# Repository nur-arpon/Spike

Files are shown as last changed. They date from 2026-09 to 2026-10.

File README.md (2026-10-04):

# Spike

**A desk robot dog with a face, a memory and a personality, and the apps that bring him to life.**

Spike (the hardware project is called *Desk Buddy*) is a small four-legged companion that lives on your
desk. His face is a 4.3-inch touch screen. He hears you, sees you, remembers what you tell him, wakes you
up, teases you when you're fine and goes gentle when you're not. When he's away from the robot body, the
same character lives on your phone and your Windows PC.

> **All rights reserved. This repository is source-available for viewing only.**
> No licence is granted to copy, modify, build, distribute or use any part of it. See [LICENSE](LICENSE).
> Third-party components keep their own licences: see [THIRD_PARTY_NOTICES.md](THIRD_PARTY_NOTICES.md).

<p align="center">
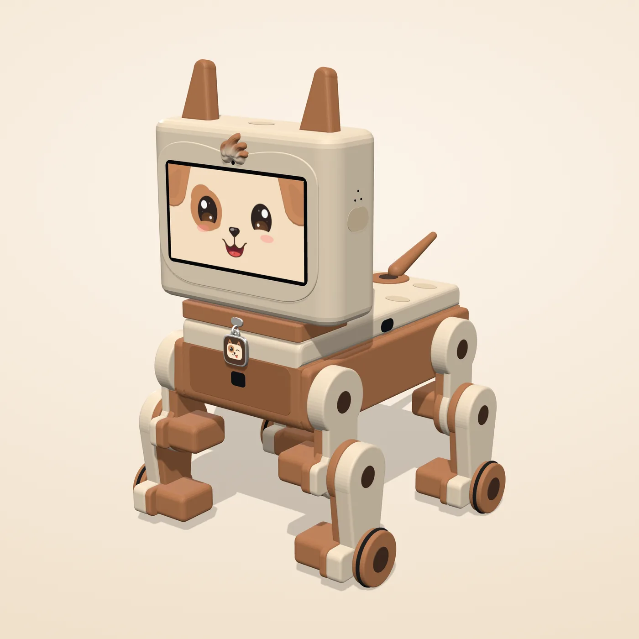
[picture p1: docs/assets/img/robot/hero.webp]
Spike, the desk robot (v3.2 design)
  
</p>

## What's in here

| Part | Folder | What it is |
|---|---|---|
| **Face** | `software/face_v2/`, `software/face/` | The animated character face (Spike the pup, Spicy the cat): moods, expressions, games, captions and sounds, drawn procedurally. A browser build doubles as the reference the firmware is tested against. |
| **Brain** | `software/laptop/spike_brain/` | The mind that runs on your own computer: wake words, speech recognition, conversation, persona, long-term memory, alarms and reminders, vision events and a natural voice. Private by design: speech, vision and memory stay on the laptop. |
| **Firmware** | `software/firmware/` | ESP32-S3 firmware for the two boards: the screen board (face renderer, body control, gait, sensors, Bluetooth LE and Wi-Fi link) and the camera board. Pixel-checked against the browser face. |
| **Protocol** | `software/protocol/` | The one contract between robot, brain and apps: message types, the BLE framing and the test vectors every side checks itself against. |
| **App** | `software/app/spike_app/` | One Flutter codebase for Android and Windows. Pair and talk to Spike, drive him, teach him tricks, design faces in the Face Studio, set alarms, see what he remembers and make him forget, and meet him in 3D. On the phone he can also run "away" with an on-device brain. |
| **CAD** | `cad/` | The printed body, generated by Python scripts driving SolidWorks: every part, the bought-parts model, full assemblies, STL exports, renders and build reports, versions v1 to v3.2. |
| **Assembly guide** | `guide/` | The illustrated build guide (PDF), generated from the CAD and the parts list. |
| **3D previews** | `preview_3d/` | Interactive shell-design previews used to choose the look. |
| **Website** | `docs/` | The official site, published with GitHub Pages at <https://nur-arpon.github.io/Spike/>. How to post an update: [docs/UPDATING.md](docs/UPDATING.md). |

## A look at it

<p align="center">
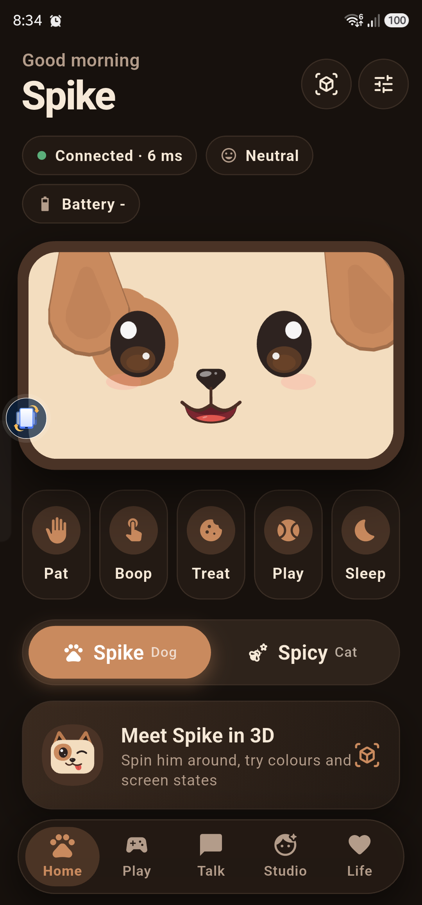
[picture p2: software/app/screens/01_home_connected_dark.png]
Spike app, home screen
  
  &nbsp;
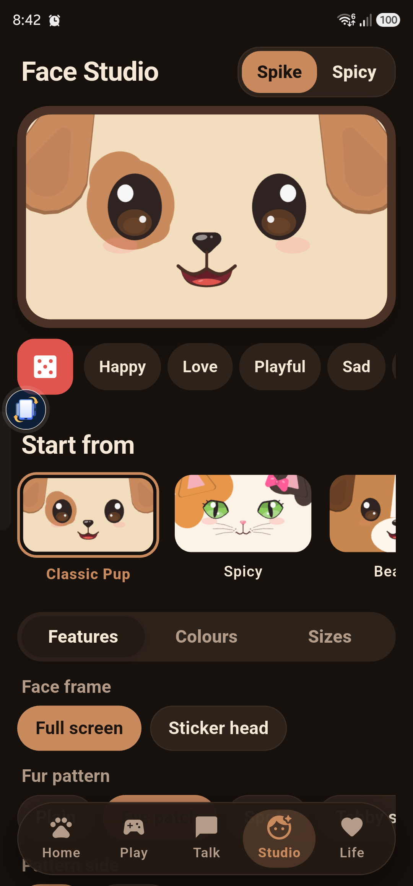
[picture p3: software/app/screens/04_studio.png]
Face Studio
  
  &nbsp;
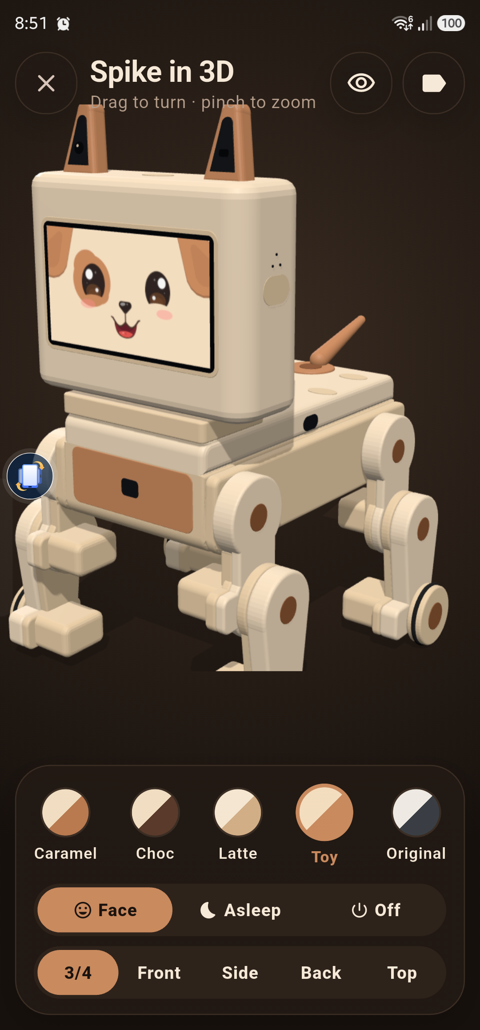
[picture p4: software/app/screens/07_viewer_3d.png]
Spike in 3D
  
</p>

<p align="center">
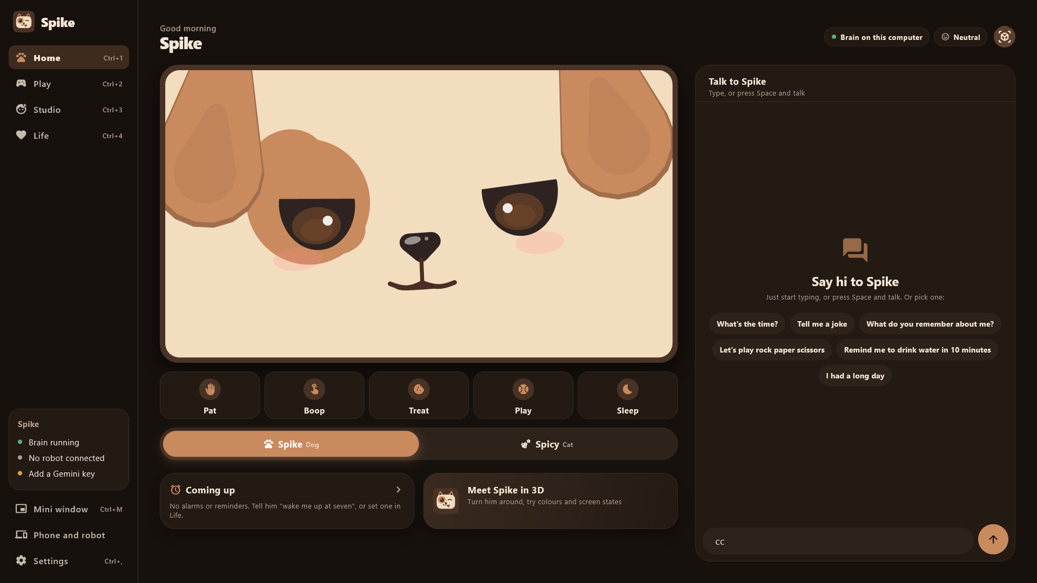
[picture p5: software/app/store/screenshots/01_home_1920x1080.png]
Spike for Windows
  
</p>

## The hardware, briefly

- **Head:** ESP32-S3 board with a 4.3-inch capacitive touch screen, two microphones, a speaker and a touch pad.
- **Camera:** a second ESP32-S3 with an OV5640 camera, its lens under a tuft of fur in the middle of the forehead; a gesture sensor sits in the chest.
- **Body:** thirteen micro servos (hips, knees, wheel paws and a tail) on two PWM drivers, an IMU, capacitive
  touch pads, and time-of-flight sensors that stop him at the desk edge. Desk-edge stops live in the
  firmware and cannot be turned off from any app.
- **Power:** a single 18650 cell with protection, a fuse and USB-C charging.
- **Shell:** fully 3D-printed in two colours; every servo, horn, screw and wire is hidden inside.

## Privacy

Spike's brain runs on the owner's own computer. There are no accounts, no ads and no tracking. The app's
privacy policy is published at **<https://nur-arpon.github.io/Spike/privacy-policy.html>**.

## Status

Active development, 2026. Follow along at <https://nur-arpon.github.io/Spike/updates.html>.

- App 1.0.1 (Android and Windows) and the laptop brain run together today.
- Firmware for both boards builds, and its protocol and face-rendering tests pass.
- The v3.2 body (one screen face, camera under a forehead tuft) is designed and checked; the first print is next.

## Licence

Made by Nur Ifran Arpon · SpaceZ.

Copyright (c) 2026 Nur Ifran Arpon (SpaceZ). All rights reserved. Viewing only; see [LICENSE](LICENSE).
For licensing enquiries, open an issue.

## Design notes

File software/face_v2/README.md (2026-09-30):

# Spike's face, version 2

This folder is the new face for Spike, and for Spicy, his cat side. It runs in your web browser as a simulator of the robot's little screen. Everything works offline. There are no downloads and no internet calls, and every sound is made live by the browser.

Version 1 is still in the folder next to this one, called "face". Nothing in it was changed.

## How to open it

Double-click the file called index dot html. It opens in your browser. There is nothing to install.

## What is new in version 2

The face sits lower on the screen now, the way baby animals look. The eyes are just below the middle, and the nose and mouth are tucked in close underneath.

Nothing joins the two eyes any more. The line that looked like the rim of glasses is gone. There is a test that checks this every time.

The default face is your toy puppy. It has cream fur, a brown patch around one eye, big glossy dark eyes with two shiny highlights, a wet dark nose, a big smile with a red tongue, and floppy brown ears in the top corners.

Spicy has her own face. She is a calico cat, which is a nice touch, because calico cats are almost always girls. She has green cat eyes with eyelashes, a pink nose, a little "w" shaped mouth, whiskers and a pink bow. When she's calm she looks at you with half-closed, knowing eyes.

## Why it looks alive

Nothing on the face ever snaps. Every part moves like it is on a soft spring, so it overshoots a little and settles, the way a cartoon character moves.

When Spike blinks, his eyes squash shut and then stretch a little as they spring open. Sometimes he blinks twice.

His eyes make tiny darting movements all the time, and bigger glances now and then. The shiny spots in his eyes stay put as he looks around, like real reflections.

He breathes with a slow gentle bob. His ears flick now and then, and they swing when he tilts his head. He sniffs in little bursts of three, and his nose twitches when he's curious. Now and then he tilts his head at you.

When he is really happy, his cheeks push his eyes up into happy closed arcs. When he is sad, his eyes get watery with a wobbling waterline and extra sparkles.

## Touching the face

Click anywhere on the face to give him a head pat. His eyes close happily, his ears go flat, and little hearts pop up. If you pat too fast he gets dizzy. Spicy only puts up with a few pats before she gets cross and hisses.

Click his nose to boop it. He goes cross-eyed looking at his own nose, then giggles.

Move your mouse around and his eyes follow you. On the real robot the camera will do this.

## The panel on the right

The panel has four tabs.

Moods has one button for every mood. There are forty-three of them, from happy and sad to jealous, smug, awe and hungry. Each mood has its own little motion, so none of them is a still picture. "Play all moods" steps through every one.

Actions has the physical actions. They are wake up, fall asleep, nap, doze off, dream, trip, sneeze, hiccups, shiver, pant, happy dance, zoomies, head tilt, sniff around, beg, roll over and play bow. Each one also sends a body label, which the robot's legs and wheels will use later. You can see the label under the buttons while an action plays.

Life has the everyday things. You can say hi, get a greeting that suits the time of day, and try events like coming home, looking sad, being picked up, falling over, being ignored, talking, and a wake-up alarm with an "I'm up!" button. There is a battery slider too. Low battery makes him hungry. He gives you big pleading wet eyes, licks his lips, drools a little, his tummy rumbles, and a small battery blinks red above his head. On the Minimal and Night robot styles the battery shows in his eyes instead. Tick "Charging" and he eats happily until he's full. You can also play a song and he dances and sings along, or play rock, paper, scissors.

Face Studio is where you build your own pet face. It is explained next.

The buttons at the top switch between Spike and Spicy, turn the sound off, and show the face at its true size on the robot.

## The Face Studio

Every part of the face can be swapped. You can choose the fur colour and pattern, the eye style, shape and colour, eyelashes, eyebrows, nose, mouth, ears, cheeks and freckles, whiskers, and an accessory like a bow, bandana, glasses, a party hat or a flower.

Whatever you choose, the face still does every mood, every blink and every action. That is the most important rule of the Studio, and the tests check it with random faces.

There are nine ready-made faces to start from. They are Classic Pup, Spicy, Beagle, Husky, Minimal, Night, Anime Pup, Sticker Buddy and Midnight Tux. Minimal is white glowing eyes on black. Night is dim and warm for a dark bedroom.

"Roll the dice" makes a random face from colours that go well together.

There are three save slots, kept in this browser.

Each face also has a share code, a short line of letters starting with S P K 1. Copy it to share a face, and paste one in and press Load to use someone else's.

Spike and Spicy each keep their own face, so changing one doesn't change the other.

## Changing the names

The names and wake words live in one place, the file called config dot js. If you rename Spicy there, the whole page follows. That includes the buttons, the speech bubbles and the Face Studio.

## For the robot

The face only uses shapes the robot's screen library can draw: filled circles, ellipses, rounded rectangles, triangles, thick lines and arcs, with see-through blending. There are no blurs or glows. The eyelids aren't black bars. The eye is simply drawn only between the lid edges, so the lid you see is the real fur underneath.

The tool called export recipes writes every mood, face, preset and action into one data file for the robot's code.

## Checking it works

The automatic test is test slash smoke dot js. You run it with node, and at the moment it passes all of its twenty thousand checks. It draws every mood with every ready-made face and twenty random faces, for both Spike and Spicy. It also measures that the eyes, nose and mouth sit where you asked, checks that nothing is drawn between the eyes, and runs every event, action, the song and the battery.

A second check loads the real page without a browser and clicks through it. It is tools slash page check dot js, and it passes all forty-one checks. The page also fits narrow windows and phones now. The face shrinks to fit, and under about 900 pixels wide the controls move below the face.

The pictures of every face and every action are in the tools slash out folder.

## Not finished yet

The face hasn't been put on the real robot screen yet. The export file and the design notes are ready for that.

The speech lines are still a fixed list. Later they'll come from the laptop AI.

The battery slider is a test control. On the robot, the real battery reading will drive it.

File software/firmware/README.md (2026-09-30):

# Spike's firmware: how to put it on the robot

This page is written to be read aloud. It tells you how to load Spike's software onto the two boards
when they arrive, one step at a time, and what you should see after each step.

## What is in this folder

There are two programs. The first one goes on the screen board, the big Guition board with the 4.3 inch
screen. It draws Spike's face, runs his whole personality, plays his sounds, listens with the two
microphones, talks to the laptop, and drives all thirteen servos and every sensor. The second program goes
on the small camera board in the muzzle. It only sends pictures to the laptop.

Spike does not need the laptop to be alive. Without it he still blinks, looks around, gets bored and falls
asleep, loves head pats, giggles when you boop his nose, gets scared at the desk edge, and gets hungry
when his battery is low. The laptop adds talking, seeing you, alarms and games.

## Before you start

You need the laptop, one data-capable USB-C cable, and this project folder. The build tool is already
installed inside the laptop brain's Python environment, so you do not need to install anything else.

Every command below is typed into a Windows terminal. Wherever a command starts with pio, type the full
path instead: D colon, backslash, Claude-Projects, backslash, RobotCompanion, backslash, software,
backslash, laptop, backslash, dot venv, backslash, Scripts, backslash, pio dot exe. It is easier to copy it
from FLASHING_CHECKLIST.md, which has every command written out.

Always unplug the 5 volt lead from the board before you plug the USB cable into it. Two power sources on
one board can damage the board or the laptop's USB port. This is rule six in the assembly guide.

## Step 1: back up the screen board's factory program

Do this once, the day the screen board arrives, before you flash anything. It lets you put the seller's
demo back if you ever need to. The checklist has the exact esptool command. It reads the whole 4 megabyte
flash into a file called guition factory backup dot bin. Keep that file.

## Step 2: flash the screen board on the desk

Plug the screen board into the laptop with the USB cable. Nothing else needs to be connected for this step.
Open a terminal in the folder software, firmware, screen board, and run pio run, then pio run with the
option minus t upload. The first build takes a few minutes. When it finishes, the board restarts by itself.

What you should see: Spike's face appears within about two seconds. It is the Classic Pup face: cream fur,
a brown patch around one eye, big glossy eyes. He blinks, his eyes dart around, and his ears twitch.
If you touch his nose he goes cross-eyed and giggles. If you touch anywhere else he gets a happy squish and
little hearts pop up.

Now open the monitor with pio device monitor. You should see lines that start with display, touch and
audio, and every ten seconds a line that starts with face, which tells you the frame rate. Please write
down the frame rate and the render time from that line. They tell us whether the face is fast enough.
On the bench, without the robot's body attached, the body lines will say that no servo board was found.
That is expected.

If the screen stays black, check the monitor for a line saying PSRAM allocation failed. If the face shows
but touching does nothing, the monitor will say GT911 not found, and the touch pins need checking. Both
are listed in OPEN_QUESTIONS.md.

## Step 3: tell Spike about your Wi-Fi and the laptop

The first time Spike starts without any saved Wi-Fi, he opens his own setup Wi-Fi network called Spike
Setup, followed by six letters and numbers. Join it with your phone. A setup page opens by itself. If it
does not, open a browser and go to 192.168.4.1. Type your home Wi-Fi name, your Wi-Fi password, the
laptop's IP address, and the pairing token from the brain's settings file, the value called SPIKE TOKEN.
You can also set an update password there. Press Save. Spike restarts and joins your Wi-Fi.

You can do the same thing by typing into the monitor instead. Type help to see the commands. For example,
type wifi, then your network name in quotes, then your password in quotes. Then type brain followed by
the laptop's IP address, then token followed by the pairing token, then reboot.

Remember that the laptop's Wi-Fi must be set to Private in Windows, the firewall must allow the brain's
port, which is 8765, and the router's 2.4 gigahertz band must be on.

What you should see: start the brain on the laptop. Within a few seconds the monitor says brain hello,
and the brain's window shows that a face client connected. Say "Spike" and he should perk his ears.

## Step 4: flash the camera board

Unplug the camera board's 5 volt lead, plug it into the laptop, and run the same two commands in the
folder software, firmware, camera board. Then set it up the same way as the screen board: its setup
network is called Spike Cam Setup. One extra setting matters here. Type robot, followed by the screen
board's device id. The screen board prints its id at startup, and it looks like spike, dash, and six
letters and numbers. This tells the laptop that both boards belong to the same dog.

What you should see: the camera's monitor says camera sensor PID 5640, which means the OV5640 camera
answered. Once it is linked, every thirty seconds it reports how many frames it sent. If it says camera
init failed, the camera pins need checking against the seller's pin sheet. That is item eight in
OPEN_QUESTIONS.md.

## Step 5: the body, after the wiring chapter of the guide

Do this only after chapter 4 of the assembly guide, with the robot propped on a block so the legs and
wheels are in the air. The guide's servo test sketch is used first, to centre the servos and find each
wheel's stop point. Write every number into the guide's calibration table.

Then flash the Spike firmware again. At startup the monitor lists each servo board, each of the seven
lasers, the motion sensor and the touch board. The servos come on one at a time, about a sixth of a second
apart, legs first, so the power supply is never asked for a big surge.

Now type your calibration numbers in. Type servo show to see all thirteen joints and their numbers. For
each joint, type servo center, the joint number, and the pulse from your table. Then type servo test and
the joint number. The joint should move its foot forward, toward the head, for one second. If it moves
backward instead, type servo dir, the joint number, and minus one. When everything is right, type servo
save. The numbers are kept even when the power is off.

Type servo sensors to see one reading from every laser, the motion sensor, the touch pads and the battery.
On the desk the three desk-edge lasers should read roughly 80 to 110 millimetres (about 94 is expected).
Spike measures this level reading by himself when he stands still for a second after starting, and his
"this is an edge" limit becomes that reading plus 25 millimetres. Hold the nose out over the edge of the
desk: the front ones should jump far above that limit, and Spike should look scared and whine.

Walking and giving a paw come after that. Type gait help to see the commands, and follow section 5d of
FLASHING_CHECKLIST.md step by step: first the balance calibration (gait cal), then one paw held up
(gait lift left 30), then a short walk (gait walk 4), then give paw (gait paw left).

## Step 6: away from home, with your phone as Spike's brain

Firmware version 0.2.0 lets your phone be Spike's brain when the laptop is not around. The phone talks to
the screen board over Bluetooth, and when the camera or heavy traffic is needed, the phone makes a Wi-Fi
hotspot and both boards join it. At home the laptop always wins: while the laptop is connected, Spike
politely tells the phone he is busy, and the phone app switches to talking to the laptop.

First, a one-time bench step, so that the camera board can follow Spike onto the phone's hotspot. Plug the
screen board into the laptop, open the monitor, and type linkkey. Spike prints a line that starts with the
word linkkey, followed by sixty-four letters and numbers. That is the robot's own secret key, made on its
first start. Copy that whole line. Then plug in the camera board, open its monitor, paste the line and
press enter. The camera board says the key is saved. Restart the camera board. You only ever do this once
per robot, and a factory reset does not remove it. Keep that line private: do not put it in a photo or a
chat. If you ever need to, typing linkkey forget on the camera board removes it.

Second, pairing your phone. In the Spike app, look for Spike nearby. He shows up as Spike, a dash, and six
letters and numbers. When you pair, Spike shows six big digits on his face with a blue bar that shrinks,
and your phone asks you to type a code. Type the six digits within one minute. If you are too slow, just
try again: Spike makes a new code every time. Only someone who can see Spike's face can pair, and your
phone stays paired after that, so next time it connects by itself. Spike remembers up to four phones; a
fifth one replaces the phone that was used longest ago.

To see the Bluetooth state, type ble in the screen board's monitor. It shows whether a phone is connected,
whether it is paired, and the list of paired phones. Typing ble forget removes every paired phone, and so
does a factory reset. Typing status now also prints a links line: which brain Spike follows, which Wi-Fi he
is on, and whether the camera reached the phone's hotspot.

A few things to know. The phone's hotspot must be on the 2.4 gigahertz band, because the boards have no 5
gigahertz radio. On iPhones, turn on Maximise Compatibility in the Personal Hotspot settings. The robot
never saves the hotspot name or password; after a restart he goes back to your home Wi-Fi. While he is on
the phone's hotspot, wireless updates are switched off. Away from home the phone listens and speaks for
Spike, so his own microphones rest and his mouth moves to the phone's voice.

## What keeps Spike safe

All of this runs on the robot itself and never waits for the laptop. If a desk-edge laser loses the desk,
the wheels slow to a stop within about a tenth of a second, gently enough not to yank the legs, and
from full speed he stops in about 12 millimetres. If the robot is picked up or falls over, the wheels stop
and the legs relax. At 7.0 volts Spike warns that his battery is low, and at 6.8 volts he lies down and
switches all his servos off until you charge him and switch him on again. If the software ever freezes,
a supervisor switches the servo outputs off within a third of a second, and the watchdog restarts the
board within three seconds. While it restarts, the 2.2 kilohm resistor holds the servo boards off.

## Wireless updates

Once you have set an update password, you do not need the USB cable any more. Set the password in an
environment variable called SPIKE OTA PASSWORD, then run pio run with the option minus e ota, the option
minus t upload, and the option upload port followed by the robot's IP address. The servos switch off
during an update. If an update fails halfway, the old firmware keeps running.

## If something goes wrong

The monitor always tells you what the robot sees. Type status for Wi-Fi, laptop and battery, and servo
sensors for the body. Type factory reset to erase all the settings and start again with the setup network.
OPEN_QUESTIONS.md lists everything the firmware had to guess before the parts arrived, and how to check
each one on the first day.

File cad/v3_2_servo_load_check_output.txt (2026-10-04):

Desk Buddy v3.2 servo load check   mass 1025 g (W = 10.06 N)
  leg below the hip 67.6 g x 4, body 755 g, body CoM z +14.0 y 46.8
  MG90S stall 1.8 kg.cm at 4.8 V (2.2 at 6.0 V); hold limit 35% of stall = 0.63 kg.cm; dynamic factor 1.5
  columns: static / x1.5 dynamic torque (kg.cm), stall margin = stall / dynamic, hold margin = hold limit / static

FIRMWARE POSES (body attitude at the end pose; foot loads in N)
  stand         pitch  -0.0 deg roll  -0.0 deg  CoM z +12.4  FL 2.75  FR 2.73  BL 2.29  BR 2.27
  sit           pitch  +4.0 deg roll  -0.0 deg  CoM z +11.1  FL 2.75  FR 2.73  BL 2.55  BR 2.53
  lie / park    pitch  -0.0 deg roll  +0.0 deg  CoM z +12.4  FL 2.76  FR 2.75  BL 2.29  BR 2.27
  play bow      pitch  -3.9 deg roll  +0.0 deg  CoM z +13.2  FL 3.11  FR 3.10  BL 2.29  BR 2.27
  lean left     pitch  -0.0 deg roll  -0.9 deg  CoM z +12.4  FL 2.80  FR 2.73  BL 2.34  BR 2.27
  lean right    pitch  -0.0 deg roll  +0.9 deg  CoM z +12.4  FL 2.75  FR 2.78  BL 2.29  BR 2.32
  lean forward  pitch  -1.2 deg roll  -0.0 deg  CoM z +12.9  FL 2.90  FR 2.88  BL 2.29  BR 2.27

ONE PAW LIFTED (stand pose, three legs carry the robot)
  lift FL: FR 5.49 N  BL 5.05 N  BR -0.48 N   TIPS OVER (CoM outside the triangle)
  lift FR: FL 5.49 N  BL -0.44 N  BR 5.01 N   TIPS OVER (CoM outside the triangle)
  lift BL: FL 5.05 N  FR 0.44 N  BR 4.57 N   stable
  lift BR: FL 0.48 N  FR 5.01 N  BL 4.57 N   stable

case                         joint      foot N static    dyn stall x hold x  verdict
stand                        hip FL       2.75   0.01   0.02   82.89  43.52  OK
stand                        knee FL      2.75   0.01   0.01   99.00  87.03  OK
stand                        hip FR       2.73   0.01   0.02   82.89  43.52  OK
stand                        knee FR      2.73   0.01   0.01   99.00  87.03  OK
stand                        hip BL       2.29   0.00   0.00   99.00  99.00  OK
stand                        knee BL      2.29   0.01   0.01   99.00  87.03  OK
stand                        hip BR       2.27   0.00   0.00   99.00  99.00  OK
stand                        knee BR      2.27   0.01   0.01   99.00  87.03  OK
sit                          hip FL       2.75   0.05   0.07   24.33  12.77  OK
sit                          knee FL      2.75   0.03   0.04   43.94  23.07  OK
sit                          hip FR       2.73   0.05   0.07   24.47  12.85  OK
sit                          knee FR      2.73   0.03   0.04   44.18  23.20  OK
sit                          hip BL       2.55   0.23   0.35    5.15   2.70  OK
sit                          knee BL      2.55   0.50   0.75    2.40   1.26  OK
sit                          hip BR       2.53   0.23   0.35    5.18   2.72  OK
sit                          knee BR      2.53   0.50   0.74    2.42   1.27  OK
lie / park                   hip FL       2.76   0.14   0.21    8.61   4.52  OK
lie / park                   knee FL      2.76   0.49   0.74    2.45   1.28  OK
lie / park                   hip FR       2.75   0.14   0.21    8.64   4.54  OK
lie / park                   knee FR      2.75   0.49   0.73    2.47   1.29  OK
lie / park                   hip BL       2.29   0.11   0.17   10.74   5.64  OK
lie / park                   knee BL      2.29   0.38   0.58    3.13   1.64  OK
lie / park                   hip BR       2.27   0.11   0.17   10.80   5.67  OK
lie / park                   knee BR      2.27   0.38   0.57    3.16   1.66  OK
play bow                     hip FL       3.11   0.29   0.43    4.15   2.18  OK
play bow                     knee FL      3.11   0.64   0.95    1.89   0.99  MARGINAL
play bow                     hip FR       3.10   0.29   0.43    4.17   2.19  OK
play bow                     knee FR      3.10   0.63   0.95    1.90   1.00  MARGINAL
play bow                     hip BL       2.29   0.09   0.13   13.84   7.26  OK
play bow                     knee BL      2.29   0.06   0.09   20.46  10.74  OK
play bow                     hip BR       2.27   0.09   0.13   14.01   7.35  OK
play bow                     knee BR      2.27   0.06   0.09   20.66  10.85  OK
lean left                    hip FL       2.80   0.09   0.13   13.82   7.25  OK
lean left                    knee FL      2.80   0.29   0.43    4.18   2.19  OK
lean left                    hip FR       2.73   0.01   0.02   82.89  43.52  OK
lean left                    knee FR      2.73   0.01   0.01   99.00  87.03  OK
lean left                    hip BL       2.34   0.06   0.10   18.50   9.71  OK
lean left                    knee BL      2.34   0.22   0.33    5.40   2.83  OK
lean left                    hip BR       2.27   0.00   0.00   99.00  99.00  OK
lean left                    knee BR      2.27   0.01   0.01   99.00  87.03  OK
lean right                   hip FL       2.75   0.01   0.02   82.89  43.52  OK
lean right                   knee FL      2.75   0.01   0.01   99.00  87.03  OK
lean right                   hip FR       2.78   0.09   0.13   13.87   7.28  OK
lean right                   knee FR      2.78   0.29   0.43    4.21   2.21  OK
lean right                   hip BL       2.29   0.00   0.00   99.00  99.00  OK
lean right                   knee BL      2.29   0.01   0.01   99.00  87.03  OK
lean right                   hip BR       2.32   0.06   0.10   18.59   9.76  OK
lean right                   knee BR      2.32   0.22   0.33    5.45   2.86  OK
lean forward                 hip FL       2.90   0.13   0.20    9.11   4.78  OK
lean forward                 knee FL      2.90   0.32   0.48    3.71   1.95  OK
lean forward                 hip FR       2.88   0.13   0.20    9.15   4.80  OK
lean forward                 knee FR      2.88   0.32   0.48    3.74   1.96  OK
lean forward                 hip BL       2.29   0.03   0.05   38.48  20.20  OK
lean forward                 knee BL      2.29   0.03   0.04   47.00  24.68  OK
lean forward                 hip BR       2.27   0.03   0.05   38.90  20.42  OK
lean forward                 knee BR      2.27   0.03   0.04   47.34  24.85  OK
lift BL (stand)              hip FL       5.05   0.01   0.02   82.89  43.52  OK
lift BL (stand)              knee FL      5.05   0.01   0.01   99.00  87.03  OK
lift BL (stand)              hip FR       0.44   0.01   0.02   82.89  43.52  OK
lift BL (stand)              knee FR      0.44   0.01   0.01   99.00  87.03  OK
lift BL (stand)              hip BR       4.57   0.00   0.00   99.00  99.00  OK
lift BL (stand)              knee BR      4.57   0.01   0.01   99.00  87.03  OK
lift BR (stand)              hip FL       0.48   0.01   0.02   82.89  43.52  OK
lift BR (stand)              knee FL      0.48   0.01   0.01   99.00  87.03  OK
lift BR (stand)              hip FR       5.01   0.01   0.02   82.89  43.52  OK
lift BR (stand)              knee FR      5.01   0.01   0.01   99.00  87.03  OK
lift BR (stand)              hip BL       4.57   0.00   0.00   99.00  99.00  OK
lift BR (stand)              knee BL      4.57   0.01   0.01   99.00  87.03  OK
crawl, stride hip +-10       front hip    5.14   1.07   1.60    1.12   0.59  OVERLOAD
crawl, stride hip +-10       front knee   5.16   0.77   1.16    1.55   0.82  MARGINAL
crawl, stride hip +-10       rear hip     5.04   1.14   1.71    1.05   0.55  OVERLOAD
crawl, stride hip +-10       rear knee    5.04   0.79   1.18    1.52   0.80  MARGINAL
crawl, stride hip +-20       front hip    5.14   1.36   2.04    0.88   0.46  OVERLOAD
crawl, stride hip +-20       front knee   5.21   0.81   1.21    1.49   0.78  MARGINAL
crawl, stride hip +-20       rear hip     5.00   1.42   2.12    0.85   0.44  OVERLOAD
crawl, stride hip +-20       rear knee    5.01   0.82   1.23    1.47   0.77  MARGINAL
spin in place (mu 0.6)       hip FL       2.75   1.10   1.65    1.09   0.57  OVERLOAD
spin in place (mu 0.6)       knee FL      2.75   0.69   1.03    1.75   0.92  MARGINAL
spin in place (mu 0.6)       hip FR       2.73   1.13   1.70    1.06   0.56  OVERLOAD
spin in place (mu 0.6)       knee FR      2.73   0.70   1.05    1.71   0.90  MARGINAL
spin in place (mu 0.6)       hip BL       2.29   1.12   1.67    1.08   0.56  OVERLOAD
spin in place (mu 0.6)       knee BL      2.29   0.69   1.03    1.75   0.92  MARGINAL
spin in place (mu 0.6)       hip BR       2.27   1.12   1.67    1.08   0.56  OVERLOAD
spin in place (mu 0.6)       knee BR      2.27   0.70   1.05    1.71   0.90  MARGINAL
instant wheel stop (skid)    hip FL       2.75   1.71   2.57    0.70   0.37  OVERLOAD
instant wheel stop (skid)    knee FL      2.75   1.06   1.60    1.13   0.59  OVERLOAD
instant wheel stop (skid)    hip FR       2.73   1.70   2.55    0.71   0.37  OVERLOAD
instant wheel stop (skid)    knee FR      2.73   1.06   1.58    1.14   0.60  OVERLOAD
instant wheel stop (skid)    hip BL       2.29   1.41   2.12    0.85   0.45  OVERLOAD
instant wheel stop (skid)    knee BL      2.29   0.89   1.33    1.35   0.71  MARGINAL
instant wheel stop (skid)    hip BR       2.27   1.40   2.10    0.86   0.45  OVERLOAD
instant wheel stop (skid)    knee BR      2.27   0.88   1.32    1.36   0.72  MARGINAL
ramped stop 1.5 m/s2         hip FL       2.75   0.45   0.67    2.69   1.41  OK
ramped stop 1.5 m/s2         knee FL      2.75   0.28   0.41    4.34   2.28  OK
ramped stop 1.5 m/s2         hip FR       2.73   0.44   0.67    2.70   1.42  OK
ramped stop 1.5 m/s2         knee FR      2.73   0.27   0.41    4.37   2.29  OK
ramped stop 1.5 m/s2         hip BL       2.29   0.36   0.54    3.33   1.75  OK
ramped stop 1.5 m/s2         knee BL      2.29   0.23   0.35    5.19   2.72  OK
ramped stop 1.5 m/s2         hip BR       2.27   0.36   0.54    3.36   1.76  OK
ramped stop 1.5 m/s2         knee BR      2.27   0.23   0.34    5.23   2.74  OK

WORST: instant wheel stop (skid) / hip FL: static 1.71, dynamic 2.57 kg.cm -> stall margin 0.70x at 4.8 V, 0.86x at 6.0 V

WHEELS (MG90S 360, stall ~1.8 kg.cm)
  rolling resistance 0.075 N per tyre -> 0.014 kg.cm
  accelerate 0.5 m/s2: 0.128 N per tyre -> 0.023 kg.cm
  spin in place: 1.09 N per tyre -> 0.196 kg.cm (11% of stall)
  traction limit per tyre (mu 0.6): front 1.65 N, rear 1.38 N -> a max ~5.9 m/s2
  top speed (no load, 4.8 V) ~0.17 m/s

TAIL (shaft vertical: gravity gives no torque)
  wag 3.0 Hz +-30 deg: inertia torque 0.0018 kg.cm, peak speed 565 deg/s (servo max ~600 at 4.8 V) -> OK
  wag 3.0 Hz +-35 deg: inertia torque 0.0020 kg.cm, peak speed 660 deg/s (servo max ~600 at 4.8 V) -> too fast, amplitude will shrink
  wag 4.0 Hz +-40 deg: inertia torque 0.0041 kg.cm, peak speed 1005 deg/s (servo max ~600 at 4.8 V) -> too fast, amplitude will shrink
  wag 1.0 Hz +-15 deg: inertia torque 0.0001 kg.cm, peak speed 94 deg/s (servo max ~600 at 4.8 V) -> OK

POWER (servo rail = Mini560 #1, 5 V, sold as 5 A)
  holding stand         ~0.16 A
  holding sit           ~0.80 A
  holding lie / park    ~1.13 A
  holding play bow      ~1.08 A
  holding lean left     ~0.44 A
  holding lean right    ~0.43 A
  holding lean forward  ~0.58 A
  pose change while driving (all moving, 0.25 A each) ~3.2 A
  8 leg servos starting in the same 20 ms (stall-current inrush) ~7.6 A
  all 13 stalled at 1.0 A (jam, fall) 13 A
  3.2 A at 5 V -> 2.5 A from the pack at 7.2 V; sag at ~0.12 ohm pack+wiring 0.30 V
  5.0 A at 5 V -> 3.9 A from the pack at 7.2 V; sag at ~0.12 ohm pack+wiring 0.46 V
  7.6 A at 5 V -> 5.9 A from the pack at 7.2 V; sag at ~0.12 ohm pack+wiring 0.70 V

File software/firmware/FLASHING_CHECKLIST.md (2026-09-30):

# Flashing checklist (tick as you go)

Commands are for a Windows terminal (PowerShell or cmd). `PIO` below means:

    D:\Claude-Projects\RobotCompanion\software\laptop\.venv\Scripts\pio.exe

Replace `COM5` with the port Windows gives the board (Device Manager > Ports, or `PIO device list`).

## Before any USB cable goes in
- [ ] The board's 5 V lead from the hub is UNPLUGGED (guide rule 6).
- [ ] The cable is data-capable (the phone test from the BOM audit 2a.6).
- [ ] Host tests still pass on the laptop: `sh software/firmware/test/run_tests.sh` in Git Bash ends with
      `protocol check: PASS`.

## 1. Screen board - factory backup (once, first day)
- [ ] `D:\Claude-Projects\RobotCompanion\software\laptop\.venv\Scripts\python.exe %USERPROFILE%\.platformio\packages\tool-esptoolpy\esptool.py --chip esp32s3 --port COM5 --baud 460800 read_flash 0 0x400000 guition_factory_backup.bin`
- [ ] The file is 4,194,304 bytes. Keep it (restore: `write_flash 0 guition_factory_backup.bin`).
- [ ] If the port does not appear: hold BOOT, tap RESET, release BOOT, try again.

## 2. Screen board - flash on the bench
- [ ] `cd D:\Claude-Projects\RobotCompanion\software\firmware\screen_board`
- [ ] `PIO run` ends with `SUCCESS` (RAM about 42 %, Flash about 77 %).
- [ ] `PIO run -t upload --upload-port COM5` ends with `Hard resetting`.
- [ ] Face appears within 2 s (Classic Pup), blinks, looks around.
- [ ] Touch the nose: cross-eyed, squeaky boop, giggle, hearts.
- [ ] Touch elsewhere: squish, hearts, pat squeak. Six fast pats: dizzy.
- [ ] Speaker plays the sounds (if silent: OPEN_QUESTIONS B6, swap BCLK/LRCK).
- [ ] `PIO device monitor` shows `display:`, `touch: GT911 at 0x5D`, `audio:` lines.
- [ ] Write down the `face: .. fps, render .. ms avg / .. ms max` line: ______ fps, ______ ms, ______ ms.
- [ ] Bench only: `body: servo board A (0x40) NOT FOUND` is expected without the harness.

## 3. Screen board - Wi-Fi and brain
- [ ] Windows: home Wi-Fi set to Private; firewall allows TCP 8765; router 2.4 GHz band on.
- [ ] Setup: join `Spike-Setup-xxxxxx`, fill the page (Wi-Fi, laptop IP, port 8765, SPIKE_TOKEN, update
      password), Save. Or in the monitor:
      `wifi "Home Network" "password"`, `brain 192.168.1.20`, `token <SPIKE_TOKEN>`, `otapass <pw>`, `reboot`.
- [ ] Start the brain (`software\laptop\run_spike.bat`).
- [ ] Monitor: `net: connected to ws://...` then `net: brain hello`.
- [ ] Note the device id from the boot line `device spike-xxxxxx ready`: ______________.
- [ ] Say "Spike": ears perk (listening); he answers and his mouth moves with the voice.
- [ ] While he talks, the mic stream pauses (brain log: no audio from the robot until 300 ms after).

## 4. Camera board
- [ ] 5 V lead unplugged, USB in.
- [ ] `cd D:\Claude-Projects\RobotCompanion\software\firmware\camera_board`
- [ ] `PIO run -t upload --upload-port COM6`
- [ ] Monitor: `camera: sensor PID 0x5640 ... OV5640` (another id on a cheap copy is logged, not fatal).
- [ ] Setup (`Spike-Cam-Setup-xxxxxx` or monitor): Wi-Fi, `brain <laptop-ip>`, `token ...`,
      `robot spike-xxxxxx` (the screen board's id), `reboot`.
- [ ] Monitor every 30 s: `camera: N frames sent, 0 dropped`. The brain sees you (Spike's eyes follow you).
- [ ] If the picture is upside down: `flip 1 0` (or `flip 0 1`), `reboot`.

## 5. Body (after guide chapter 4, robot propped on a block)
- [ ] Guide servo sketch done: horns fitted at centre, trims and wheel stop points in the calibration table.
- [ ] Flash the Spike firmware again (step 2 upload command).
- [ ] Boot log: servo board A and B found, `7 of 7 lasers running`, MPU6050, MPR121, APDS-9960.
- [ ] Outputs switch on one by one, 150 ms apart, legs first (about 2 s in total). Nothing buzzes against a stop.
- [ ] `servo show`, then for every joint `servo center <n> <us>` from the table (wheels: the stop point).
- [ ] For every leg joint `servo test <n>`: the foot moves FORWARD first. If not: `servo dir <n> -1` (or 1).
- [ ] `servo save`. Reboot and check `body: calibration loaded`.
- [ ] `servo sensors` on the desk: desk-edge lasers about 80-110 mm (the review estimates ~94 mm), IMU about
      0 0 1 g, battery about 7.4-8.4 V. Write down the three desk-edge readings: FL ____ FR ____ REAR ____ mm.
- [ ] Stand Spike still on the desk for 2 s, then `servo sensors` again: the `desk-edge thresholds` line says
      `measured this boot` and each threshold is about the reading + 25 mm. (If it says `none: 110 mm`, he was
      not standing still and level; wait, try again. The boot log line `desk-edge level readings ...` shows it too.)
- [ ] Nose over the desk edge: that front laser jumps far past its threshold, Spike looks scared, the wheels
      would not drive forward. Same for the rear laser backing up.
- [ ] Lift the robot: `imu pickup` in the brain log, cuddly face. Put it down: `putdown`.
- [ ] Pat the head pad and the back pads: happy face, `touch head` / `touch back` in the brain log.
- [ ] Wave a hand in front of the muzzle twice: Spike says hi.
- [ ] `servo pose sit`, `servo pose lie` (shallow crouch), `servo pose play-bow`, `servo pose stand`: smooth,
      balanced, no leg hits the belly.
- [ ] `servo play happy-dance` (still on the block): tail wags (at most +-30 deg), wheels wiggle once for
      half a second. `servo play zoomies`: two half-second spins with a pause between.
- [ ] `servo off`: every servo goes limp (OE high). Reboot to restore.

## 5b. Servo load tests (cad/servo_load_check_v3_1.md, day 1)
- [ ] **Torque pass line for walking (review):** spare MG90S, powered, holding centre, a stick on the horn,
      weights hung **25 mm** from the shaft. Test 3 of the 10 servos.
      - Hold **330 g for 10 s** (that is 0.8 kg.cm, the walk's worst moment): it must not droop more than about
        2 degrees (a pen mark on the horn and the case shows it). Servo 1 ____ servo 2 ____ servo 3 ____.
      - Hold **260 g for 60 s**: same droop limit, and it must stay cool enough to hold.
      - Stall: it must lift **450 g** from 30 degrees below horizontal (1.1 kg.cm).
      - If they fail: do the 60 g coin ballast test (5d step 12) before buying anything.
- [ ] **1.1 kg.cm test:** hang 450 g on the spare MG90S horn, 25 mm from the shaft, for 5 minutes (powered,
      holding centre). Hot or buzzing = walking would need MG92B servos. Result: ______________.
- [ ] **Pod temperature:** thermometer in a front knee pod after 10 min in `servo pose lie`, then after 10 min
      in `servo pose stand`. Stop above 45 deg C. Lie: ______ deg C, stand: ______ deg C.
- [ ] **Stop test:** on the desk, away from the edge, `servo play zoomies` / a drive, then watch the front hips
      as the wheels stop: with the firmware's 1.5 m/s^2 ramp they must NOT visibly give. (The old sudden stop
      yanked them back a few degrees.)
- [ ] **Start-up dip:** watch the monitor while switching on: the outputs come on one by one (about 2 s).
      There must be no `battery dipped under 7.2 V` line at start-up, and `servo sensors` right after must
      show the battery above 7 V. If a dip line appears, note the battery voltage: ______ V.

## 5c. Away mode (firmware 0.2.0, protocol v1.3) - one-time bench step + first pairing
- [ ] Both boards run 0.2.0 (the boot line says `firmware 0.2.0`). First screen-board boot prints
      `linkkey: made this robot's link key` and `ble: advertising as Spike-xxxxxx (on)`.
- [ ] Screen board monitor: `linkkey` -> copy the whole `linkkey <64 hex>` line (keep it private).
- [ ] Camera board monitor: paste that line -> `linkkey: saved`. `reboot`. The boot log says
      `away: link key set`. (`status` on the camera shows `link key set`.)
- [ ] Phone app: find `Spike-xxxxxx`, pair. Six big digits appear on Spike's face with a shrinking blue bar;
      type them on the phone within 60 s. Monitor: `ble: phone authenticated (bonded, LE Secure Connections)`,
      then `net: phone subscribed over BLE -- saying hello` and `phone brain over BLE hello`.
- [ ] Wrong digits on purpose once: pairing fails, the digits disappear, the monitor says `pairing failed`.
- [ ] `ble` lists the phone; `status` prints the `links:` line. With the laptop brain running, the phone gets
      `busy` (the app should say the laptop is in charge).
- [ ] Laptop brain off, phone app as the brain: pat Spike's head -> the phone reacts; drive with the joystick on
      the desk (edge lasers still stop him at the edge: try it slowly).
- [ ] Phone hotspot on (2.4 GHz; iPhone: Maximise Compatibility): the app sends it -> monitor `joining the
      phone's hotspot`, `on the phone's hotspot`, `handover: telling the camera board`; the camera monitor
      says `away: joining the phone's hotspot` and `connected to the phone brain`; the app shows the camera.
- [ ] Hotspot off in the app -> both boards say `back to the home Wi-Fi`.
- [ ] Write down the `free heap / PSRAM` numbers from the 10 s face log with BLE + Wi-Fi both up: ______ / ______.

## 5d. Walking and give-paw, day 1 (cad/stability_max_research.md + the review)
Do these in order, on a hard, clear desk at least 30 cm from any edge, with a hand ready to catch him. Every
command goes into the monitor. If anything looks wrong, type `gait stop` (paw goes down gently) or
`servo off` (everything limp at once). Stop and let the servos cool if a pod feels hot to hold.
- [ ] **1. 5b torque pass line done** (330 g for 10 s). Result copied here: ______________.
- [ ] **2. IMU direction.** Spike standing. Type `gait imu`: pitch and roll both near 0 (write them down:
      ____ / ____). Lift his **nose** about 2 cm with a finger and type `gait imu` again: pitch must be
      **larger** (more +). Put him down, lift his **right** side 2 cm (so the left side is lower): roll must be **larger** (more +). If either
      goes the wrong way, stop: the IMU axes in `body_hw.cpp imuRead` must be fixed first.
- [ ] **3. Kitchen-scale balance point.** Front paws on the kitchen scale, back paws on a book of the same
      height. Scale reading ______ g, whole robot ______ g. (The model says the front carries about 45 %.)
- [ ] **4. Wheels hold with the power off.** Spike standing, a hand lightly on his back. Type `servo off`
      (all outputs off, like the walk does to the wheels). Tie a thread to one paw, run it forward over the edge of a book
      and hang 50 g on it (it pulls the paw the way its wheel rolls): the paw must **not roll**. Try all four. Also nudge him gently:
      no leg may fold (the legs are unpowered too; that is research test 6). Reboot afterwards.
      Rolls or folds: ______________ (if a wheel rolls, stop before walking).
- [ ] **5. Level desk.** Put a phone spirit-level app on the desk where he will stand: under 1 degree.
- [ ] **6. Balance calibration.** Spike standing on that spot. Type `gait cal`. He shifts his weight
      forward-and-sideways several times, tries to lift each front paw a little, then lifts each back paw
      (about 25 s). Wait for `body: gait ..., calibration passed` (or `calibration failed`) and write it down:
      FL lean ______ FR lean ______ back ______. `gait show` repeats it. Failed? Do step 12, then again.
- [ ] **7. Front-paw lift, held 30 s.** `gait lift left 30`. The log prints `gait: front-left paw up, tilt
      +x / -y deg`. **Expected: about +3.5 / -2.8** (pitch / roll), progress near 1.00. Pass: the paw is about
      4 cm up, stays up the whole 30 s without rocking, and comes down gently. Tilt ____ / ____, paw up
      ____ cm. Then `gait lift right 30`: expected about **+3.5 / +2.8**. Tilt ____ / ____.
      - While the left paw is up: slide a 1.5 mm card (two playing cards) under the **back-left** paw pod's
        inner edge. It must pass. (Right paw: the back-right pod.) Pass / fail: ______.
      - Three-paw balance check: while the left paw is up, stack coins on the front-left corner of the head
        until the paw touches down. About 90 g = the planned 8 mm margin. Coins needed: ______ g.
      - Feel the front-right and back-left hip servos afterwards: warm is fine, too hot to hold is not.
- [ ] **8. Lean direction.** Watch the `gait: paw held ..., lean now ...` lines in step 7 and in a short walk
      (`gait walk 4`). If most front lifts end with `ABORT -- lift tilt not matched in time`, type
      `gait sign -1` and repeat step 7. If that is worse, `gait sign 1` again. Sign used: ____.
- [ ] **9. Back-paw lift.** `gait walk 2 rear` (glide, back-right paw, glide, back-left paw). Each back paw rises about 1.2 cm, quietly;
      a back lift costs almost nothing, so any buzzing means the servo centre calibration is off.
- [ ] **10. First walk.** `gait walk 4`. He glides forward 4 cm, stops, lifts the front-left paw, glides,
      lifts the back-right, and so on (about 20 s). The log ends `body: gait tilt-step, done`. Then `gait walk 4 back`.
      Write down anything odd: ______________.
- [ ] **11. Desk edge while walking.** Point him at the edge from about 12 cm away: `gait walk 8`. He must
      stop **before** the edge, with all four paws down, and log `body: gait ..., edge`. Do it slowly the first time
      with a hand beside the edge. Stopped ____ cm from the edge.
- [ ] **12. 60 g rump ballast (only if steps 6/7 struggle or the torque test was weak).** Tape five
      Australian 20-cent coins (about 56 g) on top of the rump. `gait cal` again: the lean numbers should go
      **down**, and step 7 should look steadier. With coins: FL lean ____ FR lean ____. Record it: this
      decides the v3.2 ballast pocket.
- [ ] **13. 10-minute heat test.** Thermometer tip taped inside a front pod. Repeat `gait walk 16` for
      10 minutes (each one about 80 s). **Stop above 45 deg C.** Pod temperature after 10 min: ____ deg C.
- [ ] **14. Give paw.** `gait paw left`: he leans, raises the left paw about 4 cm, reaching forward, for 1.5 s.
      Then `gait paw right`. The card test from step 7 again under the opposite back pod (in this pose the
      clearance is only about 1 mm: if the card does not pass, report it -- the pod edge needs the chamfer).
- [ ] **15. Puppy-sit paw (ONLY after steps 7, 13 and 14 passed).** `gait puppy on`, then `gait paw left sit`
      with a hand ready. Card test under the back-left pod. Anything wrong: `gait puppy off` (it stays off
      until switched on again). Result: ______________.

## 6. Wireless update (optional)
- [ ] `set SPIKE_OTA_PASSWORD=<pw>` (cmd) or `$env:SPIKE_OTA_PASSWORD="<pw>"` (PowerShell)
- [ ] `PIO run -e ota -t upload --upload-port <robot-ip>`; servos switch off during the update.

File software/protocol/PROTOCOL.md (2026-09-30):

# Spike protocol, version 1

This is the one wire protocol between Spike's laptop brain and everything
that is "the robot": the ESP32 screen board, the ESP32 camera board, and the
browser face simulator (`software/face_v2`). The brain (Python,
`software/laptop/spike_brain`) implements it in `spike_brain/protocol.py`;
the simulator in `face_v2/brain_link.js`; the ESP32 firmware must implement
exactly what is written here. If code and this file disagree, this file wins
and the code is the bug.

Status: **v1.8, 2026-09-30** (backward compatible with v1.0 to v1.7; the wire
version `v` stays `1`).

Changelog:
- v1.0 (2026-09-28): first release.
- v1.1 (2026-09-28): comfort actions `snuggle` and `slowWag` (section 5.2).
- v1.2 (2026-09-29): the phone app. New role `app`; app-to-brain messages for
  the face and body, the wheels (`drive` with a dead man's switch), alarms,
  memories, the camera view and pairing; brain-to-app `timers`, `memory`,
  `robot_status`, `battery`, `camera`, `heard`, `brain_status`, `pairing`;
  brain-to-robot `drive` and `set_display`; mDNS `_spike._tcp` and the QR
  pairing link; clients on the brain's own laptop need no token. All of it is
  in **section 10**. Nothing in sections 1 to 9 changed meaning: a v1.1 robot,
  simulator or firmware keeps working unchanged (it ignores `drive` and
  `set_display` by rule 2 until it implements them).
- v1.3 (2026-09-29): away from home. The phone can be Spike's brain: a
  Bluetooth LE GATT service on the screen board carrying the same JSON
  messages (framed over the MTU, LE Secure Connections with a passkey shown on
  Spike's screen, bonding), the phone's hotspot for the camera and heavy
  traffic (`hotspot_join` / `hotspot_leave` / `hotspot_state` over BLE), the
  robot-internal ESP-NOW hand-over of the hotspot to the camera board,
  `robot_link` status and the error code `busy` (one brain at a time). All of
  it is in **section 11**. Nothing earlier changed meaning; a robot without BLE
  simply never meets a phone brain.
- v1.4 (2026-09-29): two **body actions** in `action` (section 5.2), `walk`
  and `paw`, with optional fields. Robot-side only (like the v1.1 comfort
  actions); an older robot ignores them. The robot reports how a walk ended
  with a `log` message (6.11).
- v1.5 (2026-09-30): **Spike's laptop voice on the phone** (section 10.8). An
  app may announce the cap `audio_out` with the formats it can play
  (`ogg_opus`, `pcm_s16le`); when the owner talks to Spike through that phone,
  the brain sends the reply's audio to that phone only (`say` gains `play`,
  `audio.format` may be `ogg_opus`) and the phone reports `say_state`. Nothing
  else changed: an older brain ignores the cap and plays on its own speaker; an
  older app never announces it and never gets audio.

- v1.6 (2026-09-30): **`keepalive`** (section 10.9), an app-to-brain message
  that silently keeps the language model warm and an open listening window
  open while the phone's mic session is on and the owner is quiet, replacing
  the fake head tap the app used for that (which flickered the face). The
  brain's hello says `"keepalive":true` when it understands it. Nothing else
  changed: an older brain never says so and the app then sends nothing.

- v1.7 (2026-09-30): **`voice_source`** (section 10.10): a phone with cap
  `audio_out` can say it voices its own replies (Gemini TTS on the phone,
  design rule "Gemini voice first, at home too"); the brain then sends
  those sentences as checked text only (`play: true`, `audio: null`) and
  synthesises nothing. Also optional `audio_out.voice` in the app's hello. The
  brain's hello says `"voice_source":true` when it understands it. The app now
  also sends what the phone's own recognizer heard as plain `text` (section
  10.2 is unchanged; the mic stream stays as the fallback).

- v1.8 (2026-09-30): **`voice_style`** (section 10.11) for the Windows desktop
  app's light brain, which speaks with Gemini TTS itself: the app picks each
  character's Gemini voice style (`{"type":"voice_style","mode":"dog",
  "style":"street"}`), the brain keeps it and tells every app
  (`{"type":"voice_style","styles":{"dog":"street","cat":"sassy"}}`). The
  brain's hello carries `"voice_style":{...}` only when it speaks with Gemini
  TTS; an app sends `voice_style` only to such a brain. Nothing else changed.

## 1. Transport

- WebSocket (RFC 6455). The **brain is the server**; robot boards and the
  simulator are clients.
- URL: `ws://<brain-host>:<port>/` (default port `8765`). The path is
  ignored in v1.
- One message = one **text frame** containing one UTF-8 JSON object.
  v1 never sends binary frames; a receiver that gets one ignores it.
- Size: a message must not exceed **64 KiB** (the brain refuses frames over
  256 KiB). Audio and camera data are chunked (sections 5.4, 6.7, 6.8) so an
  ESP32 never has to parse more than about 24 KiB of JSON.
- A client on the same machine (the simulator) always uses
  `ws://127.0.0.1:<port>/`, never `ws://localhost:...`: a browser may
  resolve `localhost` to `::1`, where another program can be listening.
  If the default port is taken, the brain uses the next free one and
  opens the simulator with it.
- Default bind is `127.0.0.1` (simulator only). When a real robot connects
  over Wi-Fi the brain binds `0.0.0.0` and **requires a pairing token** in
  `hello` (section 4). No audio or video crosses the network except between
  the robot and the brain on the owner's own LAN.

## 2. Envelope

Every message is a JSON object with these envelope fields:

| field  | type | req | meaning |
|---|---|-----|---|
| `v` | integer | yes | Protocol **major** version. Always `1` for this spec. |
| `type` | string  | yes | Message type (sections 5 and 6). |
| `id` | integer | yes | Sender's message counter for this connection: starts at 1, +1 per message, fits in uint32. |
| `re` | integer | no  | The `id` of the message this one answers (`hello` reply, `pong`, `error`). |
| `ts` | number  | no  | Sender's clock in milliseconds (brain: Unix epoch ms; robot: ms since boot). Logging and latency only; never used for logic. |

All other fields sit next to the envelope fields (flat object, no
`payload` wrapper), which keeps ArduinoJson filters simple.

Rules:

1. **Unknown fields are ignored**, always. New optional fields may be added
   in any v1.x without notice.
2. **Unknown `type`**: the robot ignores it silently. The brain ignores it
   and answers `error` with code `unknown_type`.
3. A message whose `v` is not `1` is answered with `error`
   `version_mismatch`; if it was the `hello`, the brain then closes with
   code 4001.
4. Field names are `snake_case`. Enum values are strings. Mood and action
   names are **exactly** the camelCase ids in `face_v2/moods.js` (`MOODS`)
   and `face_v2/actions.js` (`ACTIONS`), for example `cuteAngry`,
   `tailWagDance`. The brain has a test that fails if its lists drift from
   those files.
5. Numbers: coordinates and levels are JSON numbers; counters are integers.
6. Within v1 the meaning of an existing field never changes. Anything
   incompatible is v2.

## 3. Connection lifecycle

1. Client opens the WebSocket and sends `hello` **within 5 s**, otherwise
   the brain closes with 4000.
2. The brain answers with its own `hello` (`re` = the client's hello id).
   Until then the client sends nothing else. Messages before `hello` are
   answered with `error` `not_ready` and dropped.
3. Right after the reply the brain re-sends the current state: `set_mode`,
   then `mood`. A reconnecting robot therefore never needs to remember
   anything the brain told it.
4. **Heartbeat.** The brain sends `ping` every `heartbeat_s` seconds (from
   its hello, default 5). The client answers `pong` with `re` = the ping id.
   Either side treats the link as dead after `3 x heartbeat_s` with no
   inbound message of any kind, closes it and (client) reconnects.
   WebSocket-level ping frames are also sent by the brain; clients must
   answer them (all common libraries do this automatically).
5. **Reconnect** (client): wait 0.5 s, then 1, 2, 4, 8, and at most 10 s
   between attempts, each +-20 % random jitter; reset after a successful
   hello. On reconnect send a fresh `hello`.
6. Close codes: 1000 normal, 1001 brain shutting down, 4000 hello timeout,
   4001 version mismatch, 4002 protocol abuse (more than 20 invalid
   messages in 10 s), 4003 bad or missing token.

A physical robot with two boards opens **two connections** with the same
`device_id` and different `role`: the screen board (`role: "face"`) and the
camera board (`role: "camera"`).

## 4. hello

### 4.1 Client to brain

```json
{"v":1,"type":"hello","id":1,"role":"face","device_id":"spike-7c9e2a",
 "fw":"0.1.0","caps":["face","speaker","mic","touch","imu","edge","battery"],
 "audio_out":{"rates":[16000,22050],"format":"pcm_s16le"},
 "token":"<pairing token, only when the brain requires one>"}
```

| field | type | req | meaning |
|---|---|-----|---|
| `role` | string | yes | `simulator`, `face` (screen board), `camera` (camera board), `robot` (single-board robot), `tool` (tests, debug consoles), `app` (the phone app, v1.2, section 10). |
| `device_id` | string | yes | Stable per physical robot (ESP32: from the eFuse MAC). Simulator: random per page load is fine. |
| `fw` | string | yes | Firmware / page version, semver. |
| `caps` | string[] | yes | Capabilities, any of: `face`, `speaker`, `mic`, `camera`, `touch`, `imu`, `edge`, `battery`, `drive`, `text`. The brain only sends a client what its caps can use (`say` audio needs `speaker`; `look_at` needs `face`). |
| `audio_out` | object | no  | Speaker formats the client accepts: `rates` (Hz, preferred first), `format` (only `pcm_s16le` in v1). Default: any rate. |
| `token` | string | no  | Pairing token; required when the brain is bound to a non-loopback address. |

### 4.2 Brain to client

```json
{"v":1,"type":"hello","id":1,"re":1,"server":"spike-brain","version":"0.1.0",
 "session":"a41f","heartbeat_s":5,"mode":"dog",
 "names":{"dog":"Spike","cat":"Spicy"},
 "wake_words":{"dog":["Spike","Hey Buddy"],"cat":["Spicy"]},
 "audio":{"format":"pcm_s16le","rate":22050,"channels":1}}
```

`names` and `wake_words` come from the brain's config; clients show these
instead of their own built-in names. `audio` is the format of `say_audio`
for this client (the brain resamples to the client's first `audio_out`
rate when one is given).

## 5. Brain to robot

### 5.1 `mood`
`{"type":"mood","mood":"caring","hold_s":0}` sets the face mood.
`hold_s` (optional, default 0): keep it at least this long before the
robot's own idle life may drift it; 0 = the robot's normal rules apply.

### 5.2 `action`
`{"type":"action","action":"headTilt"}` plays a physical action (face,
sound and body). Names: the keys of `ACTIONS` in `face_v2/actions.js`
(`wakeUp`, `fallAsleep`, `napping`, `dozing`, `deepSleepDreams`,
`tripBump`, `sneeze`, `hiccup`, `shiver`, `pant`, `tailWagDance`, `zoomies`,
`headTilt`, `sniffAround`, `beggingAction`, `rollOver`, `playBow`, `yawn`,
`boop`). Unknown names are ignored.

v1.1 adds two **comfort actions** that are not in face_v2's table and must be
implemented by the robot itself (the simulator draws them in
`brain_link.js`): `snuggle` (lean in toward the owner: head dips and tilts,
eyes soften, ears relax, a small sigh; body: a slow lean forward) and
`slowWag` (a slow, contented tail wag: three soft sways; body: tail at half
speed). The brain sends them when the owner is sad, lonely or tired, where a
big happy action would feel wrong. A v1.0 robot ignores them (rule above).

v1.4 adds two **body actions**, also robot-side only (the robot owns the
motion and its safety; the brain or app only asks):

- `{"type":"action","action":"walk","direction":"forward","steps":4,"style":"auto"}`
  walks. `direction`: `forward` (default) or `back`. `steps`: 1 to 16
  (default 4), one paw step each. `style` (default `auto`): `tiltStep` (every
  paw lifts in turn, glides between), `rearStep` (back paws only), `march`
  (wheels roll, legs bob, paws stay down). The robot may use a gentler style
  than asked (no balance calibration yet, tilted desk, low battery, repeated
  aborts) and stops at a desk edge or obstacle.
- `{"type":"action","action":"paw","side":"left","from":"stand"}` offers a
  front paw. `side`: `left` (default) or `right`. `from`: `stand` (default) or
  `sit` (only if the robot has the puppy-sit variant switched on; otherwise it
  offers the paw from the stand).

When it ends, the robot sends `{"type":"log","level":"info"|"warn","msg":"gait
<style>: <result> - <why>"}`.

### 5.3 `event`
`{"type":"event","event":"comeHome"}` asks the robot to run one of its own
built-in life reflexes (face_v2 `behaviour.js`): `sayHi`,
`greetByTimeOfDay`, `comeHome`, `ownerLooksSad`, `pickedUp`, `fellOver`,
`ignoredNudge`. The robot owns the animation; the brain only says when.

### 5.4 `say` and `say_audio`
Speech is sent one sentence (a "segment") at a time so it can start before
the whole reply exists. One reply = one `utt` (utterance id, string);
its segments have `seq` 0, 1, 2, ...

```json
{"type":"say","utt":"u17","seq":0,"final":false,"text":"Oh, you're home!",
 "mood":"excited","duration_ms":1240,
 "audio":{"format":"pcm_s16le","rate":22050,"channels":1,"samples":27342,"chunks":2},
 "mouth":{"rate_hz":50,"values":[0,12,55,80,61,30,4,0]}}
```
followed by `chunks` messages:
```json
{"type":"say_audio","utt":"u17","seq":0,"index":0,"last":false,"data":"<base64>"}
```

| field | meaning |
|---|---|
| `text` | Caption for this segment (already cleaned: no tags, no emoji). |
| `final` | `true` on the last segment of the utterance. |
| `mood` | Optional mood to show when this segment starts playing. |
| `duration_ms` | Audio length of this segment. |
| `audio` | `null` for a caption-only segment (show `text` for `duration_ms`). Otherwise the PCM format, total `samples`, and how many `say_audio` chunks follow. |
| `mouth` | Mouth-open envelope aligned with the audio start: one value per `1/rate_hz` s, 0 (closed) to 100 (wide open). |
| `say_audio.data` | Base64 of raw little-endian 16-bit mono PCM, at most 8192 samples (16 KiB raw, about 22 KiB base64) per chunk. |

**End marker.** The brain streams a reply as it is written, so it may only
learn that the utterance is over after its last segment went out. It then
sends an end marker: a `say` with `text` "", `audio` null, `duration_ms` 0
and `final` true. The robot shows and plays nothing for it and does not
report `say_state` for it. Caption-only segments (`audio` null, non-empty
`text`) are reported like audio segments: `started` when shown, `finished`
after `duration_ms`.

Playback rules: segments of one `utt` play back to back in `seq` order with
no gap. A new `utt` queues behind the current one. `stop_speaking` (5.5)
cuts everything. A robot may start playing a segment as soon as its first
chunk arrives (streaming into its I2S buffer).

The robot reports playback with `say_state` (6.6). **The brain keeps the
microphone muted from the first `say` until 300 ms after the robot reports
the final segment `finished`** (with a timeout of `duration + 2 s` in case
the report is lost), so Spike never hears himself.

### 5.5 `stop_speaking`
`{"type":"stop_speaking","utt":"u17"}` stops playback now and drops queued
segments. `utt` optional: absent = everything.

### 5.6 `listening`
`{"type":"listening","state":"listening"}` where `state` is `idle`,
`wake` (heard his name or a head tap), `listening` (recording a request),
`thinking` (working on a reply), `speaking`. The face shows it (ears perk
when listening, eyes glance up when thinking).

### 5.7 `look_at`
`{"type":"look_at","x":-0.4,"y":0.1,"source":"camera"}`. Where the eyes
should look, in face-screen space as seen by a person facing the robot:
`x` -1 (screen left) to +1 (screen right), `y` -1 (up) to +1 (down).
The brain already maps camera image position to this space. Sent at most
10 times a second, only while a face is tracked.

### 5.8 `sound`
`{"type":"sound","sound":"whine"}`. Built-in synthesized sounds: `yip`,
`bark`, `whine`, `sniff`, `sigh`, `snore`, `giggle`, `meow`, `purr`,
`hiss`, `trill`, `yawn`, `sneeze`, `hiccup`, `growl` (stomach), `munch`,
`pop`, `boop`, `patSqueak`.

### 5.9 `alarm`
```json
{"type":"alarm","alarm_id":3,"state":"ringing","level":1,"label":"Wake up"}
```
`state`: `ringing` (with `level` 0 soft whine, 1 yips, 2 barks + jokes,
3 everything), `snoozed` (with `until`, Unix seconds), `stopped`. The robot
plays its own escalating alarm face and sounds; spoken jokes arrive as
normal `say` messages.

### 5.10 `game`
Rock paper scissors:
```json
{"type":"game","game":"rps","phase":"reveal","owner":"rock","robot":"paper",
 "result":"lose","score":{"owner":1,"robot":2,"draws":0}}
```
`phase`: `start`, `countdown` (with `count` 3, 2, 1), `shoot`, `reveal`,
`end`. `result` is from the **owner's** point of view (`win`, `lose`,
`draw`). `owner` may be `unknown` if nothing was seen or heard.

### 5.11 `set_mode`
`{"type":"set_mode","mode":"cat"}`: `dog` (Spike) or `cat` (Spicy).

### 5.12 `set_recipe`
`{"type":"set_recipe","mode":"dog","code":"SPK1..."}` or with `recipe`
(a face_v2 recipe object) instead of `code`. Changes the face look.

### 5.13 `ping`
`{"type":"ping"}`; answer with `pong`.

## 6. Robot to brain

### 6.1 `touch`
`{"type":"touch","zone":"head","gesture":"tap"}`. `zone`: `head`, `nose`,
`back`, `chin`. `gesture`: `tap`, `pat` (stroke), `hold`, `release`.
A head tap wakes Spike to listen; during an alarm it snoozes it.

### 6.2 `imu`
`{"type":"imu","event":"pickup"}`. `event`: `pickup`, `putdown`,
`shake`, `fall`, `lap` (held still on a lap).

### 6.3 `edge`
`{"type":"edge","sensor":"front_left","state":"edge"}`. `state`: `edge`
or `clear`. The robot's own reflex already stopped the wheels; this is
information for the brain.

### 6.4 `battery`
`{"type":"battery","percent":27,"volts":7.12,"charging":false}`. Sent on
change of at least 1 %, on charging change, and every 60 s.

### 6.5 `mood_state`
`{"type":"mood_state","mood":"sleepy","mode":"dog","action":null}`. Sent
when the robot's own engine changes mood, mode or action. A `mode` change
made on the robot (a button) is authoritative: the brain follows it.

### 6.6 `say_state`
`{"type":"say_state","utt":"u17","seq":0,"state":"started"}`. `state`:
`started` (segment began playing), `finished` (segment ended),
`stopped` (cut by `stop_speaking`).

### 6.7 `audio` (microphone)
```json
{"type":"audio","seq":1042,"rate":16000,"format":"pcm_s16le","data":"<base64>"}
```
Mono, 16 kHz, 20 to 100 ms per chunk, `seq` +1 per chunk (a gap means lost
audio; the brain carries on). The brain ignores this stream while it is
talking (mic mute), so the robot may keep streaming.

Optional `end_silence_ms` (int, v1.2 app mic): how long a silence ends a
request while this stream carries it (the app's "Wait before Spike
answers", default 3000). The brain clamps it to 1500..6000 and goes back to
its own `vad.end_silence_ms` when a chunk from that client comes without it
or the client disconnects. Older brains ignore it.

### 6.8 `camera`
```json
{"type":"camera","seq":88,"format":"jpeg","width":320,"height":240,"data":"<base64>"}
```
At most 10 frames per second, each at most 48 KiB of JPEG. Frames are
processed in memory and never stored unless the brain runs with its debug
flag.

### 6.9 `text`
`{"type":"text","text":"what's the time?"}`. Typed input from the
simulator or a tool; handled exactly like heard speech, wake word not
needed.

### 6.10 `alarm_ack`
`{"type":"alarm_ack","action":"stop"}` (`stop` or `snooze`), from a
button on the robot or simulator.

### 6.11 `log`
`{"type":"log","level":"warn","msg":"I2S underrun"}`. Optional; the brain
prints it.

### 6.12 `pong`
`{"type":"pong","re":41}`.

## 7. error (both directions)
```json
{"type":"error","re":12,"code":"bad_value","message":"unknown mood 'happpy'"}
```
Codes: `bad_json`, `missing_field`, `bad_value`, `unknown_type`,
`version_mismatch`, `not_ready`, `auth`, `too_big`, `busy` (v1.3, section
11.4: the robot already has another brain). An error never closes
the connection by itself, except the cases in section 3.

## 8. Reserved for later (do not use in v1)
`move` (come to the owner across the desk, go to the ArUco home spot),
`ota`, `config`, binary audio frames. These names are reserved.

## 9. Example session
```
robot -> {"v":1,"type":"hello","id":1,"role":"simulator","device_id":"sim-3f2a","fw":"2.0.0","caps":["face","speaker","touch","text","battery"]}
brain -> {"v":1,"type":"hello","id":1,"re":1,"server":"spike-brain",...}
brain -> {"v":1,"type":"set_mode","id":2,"mode":"dog"}
brain -> {"v":1,"type":"mood","id":3,"mood":"neutral"}
robot -> {"v":1,"type":"touch","id":2,"zone":"head","gesture":"tap"}
brain -> {"v":1,"type":"listening","id":4,"state":"listening"}
brain -> {"v":1,"type":"listening","id":5,"state":"thinking"}
brain -> {"v":1,"type":"say","id":6,"utt":"u1","seq":0,"final":true,"text":"Hi! I missed you.",...}
brain -> {"v":1,"type":"say_audio","id":7,"utt":"u1","seq":0,"index":0,"last":true,"data":"..."}
robot -> {"v":1,"type":"say_state","id":3,"utt":"u1","seq":0,"state":"started"}
robot -> {"v":1,"type":"say_state","id":4,"utt":"u1","seq":0,"state":"finished"}
brain -> {"v":1,"type":"listening","id":8,"state":"idle"}
```

## 10. The phone app (v1.2)

The Spike app on the owner's phone is a client like the robot, with
`role: "app"` in its `hello` (section 4.1 gains the role `app`). A brain older
than v1.2 answers that hello with `error` `bad_value`; the app then says hello
again as `role: "tool"` and falls back to the v1.1 behaviour (typed words).

An `app` client should announce the caps `face` (it mirrors the face, so the
brain sends it every face message like to a robot), `text` and `mic`. It must
**not** announce `speaker` (that is the robot's cap: the brain would treat the
phone as Spike's body). Since v1.5 it may announce `audio_out` instead
(section 10.8): then the phone plays the voice of the conversations that come
from it, and only those.

### 10.1 Security

- On the LAN every client needs the pairing token (section 4). Only a client
  whose TCP peer is the brain's own laptop (loopback: the simulator, or a
  phone through `adb reverse`) may leave it out (`[server] trust_loopback`).
- The types in 10.2 to 10.6 are accepted **only** from role `app`. From any
  other role they are `unknown_type`, as before. A phone can never send the
  robot's own reports: `battery`, `camera`, `say_state`, `edge`, `imu` and
  `mood_state` from an `app` client are ignored. (v1.5: `say_state` from an
  app with `audio_out` is accepted, but only for an utterance that phone is
  playing, section 10.8.)
- Message ids: fields that name a timer or a memory are `timer_id` and
  `fact_id`, never `id` (that is the envelope's message counter).

### 10.2 App to brain: the face and the body

Exactly the brain-to-robot messages of section 5, sent by the app; the brain
validates them with the same tables, updates its own state and passes them
on to every `face` client (the robot, the simulator, other phones):

| type | fields | what the brain does |
|---|---|---|
| `action` | `action` (5.2), `quiet` (bool, optional) | Plays it. For a trick the brain also answers out loud like it does to the spoken command ("Ta-da!", Spicy first refuses); `fallAsleep` says the goodnight line; `wakeUp`, `snuggle`, `slowWag`, `boop` and anything with `quiet: true` are silent. |
| `mood` | `mood`, `hold_s` (0..600) | Sets the face mood. |
| `event` | `event` (5.3) | The robot runs that reflex. |
| `sound` | `sound` (5.8) | The robot plays it (the brain's mic ignores it). |
| `set_mode` | `mode`, `quiet` (optional) | Switches Spike/Spicy; the brain announces it unless `quiet`. Same mode: the brain only echoes `set_mode` to the sender. |
| `set_recipe` | `mode`, and `code` (max 400 chars) or `recipe` (max 4 KiB of JSON) | "Wear this face": passed to every other `face` client, and **kept by the brain**, which sends it again to every robot or simulator that connects later. |
| `set_display` | `captions` (bool) | Caption bubbles on the robot's screen on or off; kept and re-sent on connect like `set_recipe`. |

`set_display` is also a new brain-to-robot type: `{"type":"set_display",
"captions":false}`. A robot that does not know it ignores it (rule 2) and keeps
showing captions.

### 10.3 Wheels: `drive`

```json
app  -> {"type":"drive","x":0.0,"y":0.6,"ttl_ms":300}
brain-> {"type":"drive","x":0.0,"y":0.6,"ttl_ms":300}     (to clients with the cap "drive")
```

- `x` turn, -1 (left) .. +1 (right); `y` speed, -1 (back) .. +1 (forward).
  Values outside are clamped; |x| and |y| under 0.02 count as 0.
  Robot mixing (arcade): `left = y + x`, `right = y - x`, each clamped to
  -1..1, then the robot's own speed caps apply.
- `ttl_ms` (100..1000, default 300): **dead man's switch.** The robot stops
  the wheels when `ttl_ms` passes without a newer `drive`. The app repeats
  `drive` about 20 times a second while the stick is held and sends one
  `x=0,y=0` on release.
- The brain forwards at most `[app] drive_rate_hz` (20) per second, newest
  value wins, a stop is forwarded at once. The brain has its own dead man's
  switch too: no `drive` from the phone within `ttl_ms` of the last one, or
  the phone disconnects, and the brain sends `x=0,y=0` itself.
- **The robot's reflexes always win.** Desk-edge, obstacle, pick-up, fall
  and low-battery stops run on the robot and filter every `drive`; no message
  can switch them off. `drive` is not the reserved `move` (section 8).
- A robot without the `drive` cap is never sent `drive`.

### 10.4 Lists: alarms, reminders and memories

Types: `timers_get`, `timer_set`, `timer_cancel` (app to brain), `timers`
(brain to app); `memory_get`, `memory_forget`, `memory_forget_all`, `memory`.

```json
app  -> {"type":"timers_get"}
brain-> {"type":"timers","items":[{"id":12,"kind":"alarm","due":1759219800,"label":"Wake up","repeat":null,"state":"active"}]}
app  -> {"type":"timer_set","kind":"reminder","due":1759219800,"label":"drink water","repeat":""}
app  -> {"type":"timer_cancel","timer_id":12}

app  -> {"type":"memory_get"}
brain-> {"type":"memory","items":[{"id":31,"text":"Arpon likes tea with honey","kind":"fact","at":1759180000}],"total":1}
app  -> {"type":"memory_forget","fact_id":31}
app  -> {"type":"memory_forget_all","confirm":true}
```

- `timers.items`: everything still to come or ringing, soonest first. `due`
  is Unix seconds; `kind` `alarm` or `reminder`; `repeat` `null` or
  `"daily"`; `state` `active`, `snoozed` or `ringing`.
- `timer_set`: `due` within the next year; `label` optional (max 80
  characters; alarms default to "Wake up"); `repeat` `""` or `"daily"`.
- `timer_cancel` of a ringing alarm stops it. An unknown or finished
  `timer_id` is answered `error` `bad_value`.
- `memory.items`: the newest `[app] memory_list_max` (200) facts, newest
  first, `text` at most 300 characters; `total` is how many there are.
- `memory_forget_all` needs `"confirm":true` (the app asks the owner first).
  It forgets facts, the mood diary and events; alarms stay.
- The brain sends `timers` and `memory` on connect and again **whenever
  they change**, whatever changed them (a voice command, another phone, an
  alarm firing). List operations are silent: the app shows the result.

### 10.5 Status for the app

| type (brain to app) | fields | when |
|---|---|---|
| `robot_status` | `online` (a robot board is connected: role `face`, `camera` or `robot`), `boards` (roles connected, the simulator included), `drive`, `camera` (bools) | on connect, and whenever a board connects or drops |
| `battery` | as 6.4 | relayed from the robot as it arrives; the last one on connect while the robot is online |
| `brain_status` | `llm`: `ready`, `warming` (starting Ollama / loading the model), `asleep` (unloaded after `[llm] idle_unload` without use; the next request wakes it), `off` (no Ollama: scripted lines) | on connect and on every change |
| `heard` | `text`, `via` (`typed`, or how it was heard), `mine` (true for the app that typed it) | every time the owner said or typed something to Spike |

### 10.6 Camera view

Types: `camera_subscribe`, `camera_unsubscribe` (app to brain), `camera`
(brain to app).

`{"type":"camera_subscribe","fps":5}` (0.5 to `[app] camera_max_fps`, 10)
makes the brain relay the robot's `camera` frames (6.8, same fields) to that
phone, newest only: a phone whose send queue is behind skips frames. It stops
on `camera_unsubscribe` or disconnect. Frames are never stored. Only frames
from the robot's own boards are relayed (never the laptop webcam).

### 10.7 Finding and pairing

- **mDNS / DNS-SD.** While it listens on the LAN the brain announces
  `_spike._tcp` on the laptop's main network address (not VPN or virtual
  adapters), port = the protocol port, TXT: `name` (Spike), `v=1`,
  `pv=1.2`, `ver` (brain version), `token=1` when a token is needed (never
  the token itself), `host` (the laptop's name). It re-announces when the
  laptop's address changes.
- **Pairing link** (shown as a QR by `python -m spike_brain --pair`):
  `spike://pair?host=<LAN IP>&port=<port>&token=<token>&name=Spike`.
  The token is `SPIKE_TOKEN` from `.env`, or, when none is set, one the brain
  makes once and keeps in `data/pairing_token.txt`.

### 10.8 Spike's voice on the phone (v1.5)

Design rule "laptop voice first": whenever the phone can reach the laptop
brain (home Wi-Fi or Tailscale), the owner hears the laptop's real voice
(Chatterbox Turbo, the voice cache, his recordings) on the phone.

**Hello.** The app adds the cap `audio_out` and says what it can play:

```json
{"type":"hello","role":"app","caps":["face","text","mic","audio_out"],
 "audio_out":{"formats":["ogg_opus","pcm_s16le"],"rates":[24000]}, ...}
```

`formats`, best first: `ogg_opus` (Ogg-encapsulated Opus, RFC 7845, mono,
about 32 kbit/s) and/or `pcm_s16le`. The brain picks the first it can make
(PCM16 if none match, or if it has no Opus encoder) and says so in its hello:
`"audio":{"format":"ogg_opus","rate":24000,"channels":1,"to_app":true}`. For
Opus the rate is the first of `rates` that Opus supports (8, 12, 16, 24 or
48 kHz), else 24 kHz.

**Where it plays (the routing rule).** A reply plays on the phone the
conversation came from, and nowhere else, when that phone has `audio_out`
and is still connected:
- the owner typed on that phone (`text`), or spoke into it (its `audio` mic
  stream fed the request, within the last 3 s, or its head `touch` started
  it), or pressed something on it that Spike answers out loud (a trick's
  "Ta-da!", goodnight, a mode switch announcement);
- the laptop's speaker and the robot's speaker then stay silent; the robot,
  the simulator and other phones get the same `say` with `audio: null` and
  the mouth timing (they show the caption and move the mouth);
- everything else (the robot's or the laptop's own microphone, alarms,
  greetings, nudges, a phone without `audio_out`) plays as before.

**Messages to that phone.** Each segment is a `say` (5.4) with `"play":true`,
followed by its `say_audio` chunks:

```json
{"type":"say","utt":"u17","seq":0,"final":false,"text":"Oh, you're home!","play":true,
 "duration_ms":1260,"mouth":{"rate_hz":50,"values":[0,12,55]},
 "audio":{"format":"ogg_opus","rate":24000,"channels":1,"samples":30240,"chunks":1,"bytes":5210}}
{"type":"say_audio","utt":"u17","seq":0,"index":0,"last":true,"data":"<base64>"}
```

- `ogg_opus`: all segments of one utterance form **one** Ogg Opus stream: the
  first segment's bytes start with the two header pages (`OpusHead`,
  `OpusTags`), later segments continue the same stream (same serial, page
  numbers and granule positions go on). Each segment is padded with silence
  to a whole 20 ms frame and ends on a page boundary, so it decodes to its
  last sample without waiting for the next one. `samples` counts the padded
  samples at `rate`; `duration_ms` = `samples` / `rate`.
- `pcm_s16le`: raw 16-bit mono samples, as 5.4.
- `data` is base64 of up to 12 KiB of the stream; `bytes` is the segment's
  total. Chunks never split across segments.
- `"play":true` with `"audio":null` = the laptop has no voice for this
  sentence: the phone says `text` with its own voice.
- The end marker (5.4) ends the utterance as usual. `stop_speaking` (5.5)
  cuts it.

**The phone** appends each segment to its player as soon as its last chunk
is in (sentences follow each other without a gap), reports `say_state`
`started` / `finished` per segment as playback passes them (the brain keeps
its mic muted until the final one, 5.4, with the same timeout), and says a
segment with its own voice (Kokoro, else Android's) when it came without
audio, its audio did not complete, or it cannot play the format. If the link
drops mid-reply it still says every segment it was told about. A brain older
than v1.5 never sends `play`, so the app plays nothing and the brain's own
speaker is heard, as before.
  When the laptop runs Tailscale (signed in, running) the link also carries
  `ts=<100.x.y.z>` and `tsname=<MagicDNS name>`, read with
  `tailscale status --json` (read-only). The app tries `host` first (home
  Wi-Fi), then `ts`, then `tsname`, with the same token, so it reaches the
  brain from any network when the phone is on the same tailnet. Older apps
  ignore the extra fields.
- `pairing_get` (app to brain) / `pairing` (brain to app):
  `{"type":"pairing_get"}` from an `app` client is answered
  `{"type":"pairing","lan":true,"url":"spike://pair?..."}` (`lan:false`,
  `url:""` when the brain is on loopback only). A phone paired over USB uses
  it to switch to Wi-Fi, or to show the QR to a second phone.

### 10.9 Keep-alive (v1.6)

`{"type":"keepalive","warm":true}` (app to brain; `warm` optional, default
true). While the owner's mic session is open and he is quiet, the app sends it
about every 2 s. The brain then (a) restarts the language model's idle-unload
timer, waking the model if it had unloaded, and (b) pushes back the end of a
listening window that is open with nothing said, so it does not time out. It
produces **no** face event, sound, `listening` message or relay to the robot,
does not count as owner interaction, and does not open a listening window that
is closed (a head `touch` does that). No reply is sent.

Detection: a brain that understands it adds `"keepalive":true` to its `hello`.
An app must send `keepalive` only to a brain whose hello has that field (an
older brain answers `unknown_type`) and otherwise sends nothing at all; it
must not fall back to a head `touch`.

### 10.10 Who voices the phone's replies (v1.7)

App to brain, any time after hello, and again after every reconnect:
`{"type":"voice_source","voice":"phone"}` or `"laptop"` (default `laptop`; the
hello may carry the first value as `audio_out: {..., "voice": "phone"}`).

- `phone`: replies routed to this phone (10.8) are sent as `say` with
  `play: true` and `audio: null`; the brain synthesises nothing and plays
  nothing on the laptop or the robot (they get the caption and mouth timing as
  in 10.8). Every sentence has passed the brain's own safety checks before it
  is sent, exactly as for its own voice. The phone speaks it (Gemini TTS, then
  its other voices).
- `laptop`: the brain's own voice, as in 10.8.
- The app switches back to `laptop` when its Gemini voice is unavailable (no
  key, free quota used up) or the owner picks "Use the laptop voice instead".
- The brain's hello says `"voice_source": true` when it understands this; an
  older brain never says so and the app never sends it (it would only earn an
  `unknown_type` error).

### 10.11 The laptop's Gemini voice style (v1.8)

The Windows desktop app runs a light brain that speaks with Gemini TTS itself
(`[tts] engine = "gemini"`, software/app/DESIGN.md "Desktop"), in the same
Google voices and style prompts as the phone (Spike: `energetic` Fenrir
(default), `upbeat` Puck, `friendly` Achird, `street` Algenib; Spicy: `sassy`
Kore (default), `smooth` Despina, `drawl` Callirrhoe, `caring` Kore).

```json
brain-> {"type":"hello", ..., "voice_style":{"dog":"energetic","cat":"sassy"}}
app  -> {"type":"voice_style","mode":"dog","style":"street"}
brain-> {"type":"voice_style","styles":{"dog":"street","cat":"sassy"}}      (to every app)
```

- `voice_style` (app to brain): `mode` `dog` or `cat`, `style` one of that
  character's ids above; anything else is answered `error` `bad_value`. The
  brain keeps the pick (it survives restarts) and sends the new picks to every
  connected app.
- The brain's hello has `voice_style` (the current picks) **only** when it
  speaks with Gemini TTS; an app sends `voice_style` only to such a brain (an
  older or non-Gemini brain would answer `unknown_type` or ignore it).
- Sad, lonely and crisis lines always use the soft direction, whatever the
  style; the safety checks are the same for every style.

## 11. Away from home (v1.3)

Away from the home Wi-Fi the **phone is Spike's brain** (the app's "phone
brain": persona, moods, commands, the language model, the safety layer). It
speaks this same protocol to the robot, exactly as the laptop brain does:
the robot is still the client of sections 3 to 6, only the pipe changes.

| Link | Pipe | Used for |
|---|---|---|
| home | WebSocket to the laptop brain (sections 1 to 10) | at home: the laptop is the brain |
| BLE | Bluetooth LE GATT (11.1 to 11.3) | away: the main phone <-> robot link |
| hotspot | WebSocket from the robot boards to the phone, over the phone's hotspot (11.5) | away: the camera, and a backup when BLE is poor |

Spike's own setup access point (the screen board's captive portal) stays for
first-time setup only; it is never a brain link.

### 11.1 The GATT service (screen board)

| What | UUID | Properties | Security |
|---|---|---|---|
| service "Spike link" | `c0de5b1e-0001-4a3c-9e5f-5370696b6500` | primary, advertised | - |
| `rx` (phone -> robot) | `c0de5b1e-0002-4a3c-9e5f-5370696b6500` | write, write without response | encrypted + authenticated (MITM) |
| `tx` (robot -> phone) | `c0de5b1e-0003-4a3c-9e5f-5370696b6500` | notify | encrypted + authenticated: the robot sends and accepts nothing until the link is encrypted, MITM-authenticated and bonded; a subscription on an unauthenticated link is answered with a Security Request (NimBLE gives every CCCD one permission, so the CCCD write itself is not refused) |
| `info` | `c0de5b1e-0004-4a3c-9e5f-5370696b6500` | read | open (nothing secret) |

- **Advertising:** connectable, the service UUID in the advertisement, the
  local name `Spike-xxxxxx` (the last 6 of `device_id`) in the scan response.
  The robot advertises whenever no phone is connected (one connection at a
  time), and keeps doing so while it is on Wi-Fi: BLE and Wi-Fi coexist.
- **`info`** is a small JSON object (at most 180 bytes), readable before
  pairing so the app can show what it found:
  `{"pv":"1.3","fw":"0.2.0","device_id":"spike-7c9e2a","brain":"lan"}`.
  `brain` is as in `robot_link` (11.4).
- **Pairing: LE Secure Connections, MITM protection, bonding.** The robot's
  IO capability is *DisplayOnly*: when a phone pairs, the robot shows a random
  6-digit passkey big on its face screen and the phone's system dialog asks the
  owner to type it. Seeing the screen is the proof of being with Spike. Legacy
  pairing and "Just Works" are refused. The robot keeps at most 4 bonds; a new
  bond when full replaces the least recently used one. `ble forget` on the
  serial console clears them all.
- **MTU:** the phone asks for 517; frames use the negotiated `ATT_MTU`.

### 11.2 Framing

A protocol message (one JSON object, UTF-8, exactly as sections 2 to 11) is
sent as one or more **frames**. Each frame is one write to `rx` or one
notification on `tx`:

```
byte 0     header: bit 7 START (first frame of a message)
                   bit 6 END   (last frame of a message)
                   bits 5..0   frame counter
bytes 1..  payload: the next piece of the message's UTF-8 bytes
```

- A message that fits is one frame with START and END both set. The frame
  payload is at most `ATT_MTU - 3 - 1` bytes (19 at the minimum MTU of 23).
- The frame counter counts every frame in that direction, 0 to 63 and round
  again, starting at 0 when the phone subscribes to `tx` (robot to phone) and
  at 0 on the first write after connecting (phone to robot).
- The receiver keeps the counter it expects next. A frame with another counter
  means frames were lost: it throws away the message it was building, takes
  the new counter, and starts collecting again at the next START frame. A
  START frame while a message is being built also starts over (the old one is
  dropped). A continuation frame (no START) while nothing is being built is
  dropped.
- A message may be at most **16 KiB** over BLE; a receiver drops a longer one
  (and answers `error` `too_big` once). `say_audio` and `camera` are never sent
  over BLE: they are too big for it and go over the hotspot (11.5).
- So a receiver never needs more than one 16 KiB message buffer per direction.

Shared test vectors for every implementation (app, firmware, fake robot):
`software/protocol/ble_frame_vectors.json`.

### 11.3 The session over BLE

- The phone waits for the robot's `hello` (up to 15 s: pairing may still be finishing) rather than relying on the subscription failing.
- When the phone subscribes to `tx`, the robot starts section 3 exactly as on
  a WebSocket: it sends its `hello` (`role` `face`, its caps, and `"link":"ble"`)
  within 5 s. No `token`: the bond is the authentication. The phone brain
  answers with its brain `hello`, then `set_mode` and `mood` (3.3).
- Heartbeat and dead link: as section 3.4 (`heartbeat_s` from the phone
  brain's hello). A BLE disconnect is a closed link.
- Reconnect: the phone (the BLE central) reconnects; the robot just keeps
  advertising. After a reconnect the robot sends a fresh `hello`.
- Everything in sections 5 and 6 works over BLE except the big messages
  above. The phone brain plays Spike's voice **on the phone** while away, so
  its `say` segments to the robot are caption-only (`audio` null) with
  `duration_ms` and the `mouth` envelope: the robot moves its mouth to the
  phone's voice and reports `say_state` as usual. The robot's microphones are
  not used away (the phone listens); a head tap still sends `touch`, and the
  phone brain starts listening on it.

### 11.4 One brain at a time: `robot_link` and `busy`

The robot follows **one brain at a time**. When `robot_link.brain` becomes `ble` or `hotspot` again (the laptop link dropped), the phone brain re-sends its state (`set_mode`, `mood`, `set_recipe`, `set_display`): what it sent meanwhile was answered `busy`.
 The laptop brain wins: while the
robot's WebSocket brain link to the home brain has completed its hello, brain
messages that arrive over BLE are ignored and answered with `error` code `busy`
(`ping`, the BLE `hello` exchange, `hotspot_join` and `hotspot_leave` are still
handled). As soon as that home link drops, the BLE brain is followed again.
The phone brain over the hotspot (11.5) is the same brain as over BLE: the
robot accepts it on both links and sends each robot-to-brain message on one
link only, the hotspot WebSocket when it is up, else BLE.

Robot to phone over BLE, on connect and whenever it changes:

```json
{"type":"robot_link","brain":"ble","wifi":"hotspot","ip":"192.168.49.23","camera":true}
```

| field | meaning |
|---|---|
| `brain` | whose commands the robot follows: `lan` (the laptop), `ble` (this phone over BLE), `hotspot` (this phone over the hotspot), `none` |
| `wifi` | `home` (joined the saved Wi-Fi), `hotspot` (joined the phone's), `off` (not joined) |
| `ip` | the robot's Wi-Fi address, or `""` |
| `camera` | optional: the camera board has joined the phone's hotspot (11.6) |

When the app sees `brain: "lan"` it connects to the laptop brain itself (the
phone is then an app of section 10 again).

### 11.5 The phone's hotspot

The camera, and any heavy traffic, need Wi-Fi. Away from home the phone
makes one (Android `startLocalOnlyHotspot`, or, when that is not possible,
the owner's own personal hotspot whose name and password the app keeps), runs
a small WebSocket server on it, and gives the robot the details **over BLE
only** (encrypted, bonded link; never over the air in the clear):

```json
phone -> {"type":"hotspot_join","ssid":"AndroidShare_1234","pass":"...","port":8766,"token":"9f2c...","host":""}
robot -> {"type":"hotspot_state","state":"joining"}
robot -> {"type":"hotspot_state","state":"joined","ip":"192.168.49.23"}
phone -> {"type":"hotspot_leave"}
robot -> {"type":"hotspot_state","state":"left"}
```

| field | meaning |
|---|---|
| `ssid`, `pass` | the hotspot's name (1..32 bytes) and WPA2 passphrase (8..63 printable ASCII characters) |
| `port` | the phone brain's WebSocket port on the hotspot |
| `token` | a one-time pairing token (16..32 characters, so the whole join fits one ESP-NOW packet, 11.6) for this hotspot session: every board's `hello` over the hotspot must carry it (section 4) |
| `host` | the phone's address on the hotspot (IPv4 or a host name); `""` = the Wi-Fi gateway (the phone is the access point) |
| `state` | `joining`, `joined` (with `ip`), `failed` (with `reason`: `not_found` (this includes a 5 GHz-only hotspot: the ESP32-S3 has 2.4 GHz only), `auth`, `timeout`, `bad_value`), `left` |

- On `hotspot_join` the screen board leaves the home Wi-Fi (if joined), joins
  the hotspot (20 s timeout), then opens its WebSocket brain link to
  `ws://<host or gateway>:<port>/` with the token and `"link":"hotspot"` in its
  hello. It also hands the hotspot to the camera board (11.6).
- The hotspot details live in RAM only, never in flash. The robot goes back to
  its saved home Wi-Fi on `hotspot_leave`, on a reboot, or when the hotspot
  link has been dead for 60 s and no phone is connected over BLE.
- The phone brain's server needs the token from every board (section 10.1
  applies); it accepts roles `face`, `camera` and `robot` only.

### 11.6 Camera board: ESP-NOW hand-over (robot internal)

The camera board has no BLE link to the phone. The screen board passes the
hotspot on over ESP-NOW, encrypted with the robot's **link key**: 32 random
bytes the screen board makes on first boot and keeps in NVS; the camera board
gets the same key once, at the bench or the factory (serial console `linkkey`
on the screen board prints it, `linkkey <64 hex>` on the camera board stores
it). Without a link key the camera board stays on the home Wi-Fi only.

ESP-NOW payload (broadcast, at most 250 bytes):

```
"SPK1" (4) | kind (1) | nonce (12) | ciphertext (n) | tag (16)
kind 1 = hotspot join: plaintext {"ssid":..,"pass":..,"port":..,"token":..,"host":..,"sid":..}
kind 2 = hotspot leave: plaintext {"sid":..}
sid = a random session id made by the screen board for each join; the camera board
obeys a kind 2 only if its sid matches the join it followed (a recorded kind 2
can't knock it off a later hotspot)
AES-256-GCM, key = link key, AAD = the first 5 bytes, nonce random per message
```

- The screen board sends it once a second on the hotspot's channel from the
  moment it has joined, until the phone confirms the camera board is online
  (`{"type":"robot_link_ack","camera":true}` over either link) or for 120 s.
- The camera board, while it has no working brain link, listens on channels 1
  to 13 in turn (1.5 s each). On a message that decrypts, it joins that
  hotspot (RAM only) and connects as `role: "camera"` with the token. `kind 2`
  or 60 s without its hotspot link sends it back to the home Wi-Fi.
- A frame that does not decrypt is ignored. Replaying an old message can at
  worst point the camera at a hotspot that no longer exists.

### 11.7 Summary of new types (v1.3)

| type | direction | link |
|---|---|---|
| `hotspot_join`, `hotspot_leave` | phone -> robot | BLE only |
| `hotspot_state`, `robot_link` | robot -> phone | BLE (also allowed on the hotspot) |
| `robot_link_ack` | phone -> robot | either |
| `error` `busy` | robot -> phone | BLE |

A laptop brain never sees any of these: they exist only between the robot and
a phone brain. The laptop brain treats them as `unknown_type` as before.

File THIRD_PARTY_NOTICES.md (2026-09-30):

# Third-party notices

Spike is proprietary (see [LICENSE](LICENSE)). It is built with, and in a few places includes, work by
others. Every component below keeps its own licence. Nothing in the Spike licence restricts your rights
under those licences to the third-party components themselves.

This repository contains **source only**. No model weights, voice models, voice recordings, virtual
environments, SDKs or build outputs are committed; the tools that fetch them download them from their
original publishers under the publishers' own terms.

## 1. Included in this repository

| Component | Where | Licence |
|---|---|---|
| three.js (Three.js Authors, 2010-2023) | inlined in `preview_3d/*.html` and `software/app/spike_app/assets/viewer3d/preview_v6.html`; the original `@license` header is kept in each file | MIT |
| flutter_secure_storage_windows (German Saprykin and contributors), patched copy | `software/app/spike_app/third_party/flutter_secure_storage_windows/` (its `LICENSE` file is kept alongside) | BSD-3-Clause |
| Flutter project templates (The Flutter Authors): Windows runner, CMake files, Android Gradle scripts, generated plugin registrants | `software/app/spike_app/windows/`, `software/app/spike_app/android/` | BSD-3-Clause |

## 2. Used by the phone and desktop app (fetched by `flutter pub get`, not included)

Declared in `software/app/spike_app/pubspec.yaml`, with exact versions in `pubspec.lock`. Each package's
licence is on its pub.dev page. Main ones:

| Package | Licence |
|---|---|
| Flutter SDK, cupertino_icons, http, crypto, path_provider, shared_preferences, url_launcher, webview_flutter, flutter_lints | BSD-3-Clause |
| flutter_riverpod, go_router, web_socket_channel, flutter_animate, flutter_svg, archive, toml, connectivity_plus, audioplayers, record, speech_to_text, flutter_tts, nsd, mobile_scanner, universal_ble, flutter_secure_storage, background_downloader, qr_flutter, window_manager, tray_manager, screen_retriever, webview_windows, flutter_launcher_icons | MIT or BSD-3-Clause (per package) |
| sherpa_onnx (k2-fsa) | Apache-2.0 |
| flutter_gemma, flutter_gemma_litertlm | per package (pub.dev) |
| flutter_soloud (SoLoud engine) | MIT / zlib |

## 3. Used by the firmware (fetched by PlatformIO, not included)

| Library | Licence |
|---|---|
| Arduino-ESP32 core (Espressif) | LGPL-2.1 |
| ESP-IDF components, esp32-camera (Espressif) | Apache-2.0 |
| ArduinoJson (Benoit Blanchon) | MIT |
| NimBLE-Arduino (h2zero) | Apache-2.0 |
| GFX Library for Arduino (moononournation) | see upstream repository |
| VL53L0X (Pololu) | see upstream repository (Pololu licence with ST API notice) |

## 4. Used by the laptop brain (installed with pip, not included)

The packaged Windows brain lists its runtime components and their licences in
`software/laptop/desktop_build/THIRD_PARTY_NOTICES.txt`. In summary: Python (PSF), NumPy and SciPy
(BSD-3-Clause), ONNX Runtime (MIT), CTranslate2 and faster-whisper (MIT), tokenizers and huggingface_hub
(Apache-2.0), Vosk (Apache-2.0), sounddevice and PortAudio (MIT), websockets (BSD-3-Clause),
python-zeroconf (LGPL-2.1-or-later), RapidFuzz (MIT), qrcode (BSD-3-Clause), comtypes (MIT). Development
and test tools also use Pillow (HPND), OpenCV (Apache-2.0), PyAV (BSD-3-Clause), MediaPipe (Apache-2.0),
pytest (MIT) and PyMuPDF (AGPL-3.0, used only by a local guide-rendering tool, never distributed).

## 5. Models and voices (downloaded on demand, never included)

| Model | Publisher | Licence |
|---|---|---|
| Whisper base.en / small.en (CTranslate2 conversion) | OpenAI / SYSTRAN | MIT |
| vosk-model-small-en-us-0.15 | Alpha Cephei | Apache-2.0 |
| Silero VAD | Silero Team | MIT |
| Kokoro-82M (via kokoro-onnx) | hexgrad | Apache-2.0 |
| Chatterbox TTS weights | Resemble AI | MIT |
| Piper voices (`en_US-*`) | Rhasspy / per-voice dataset authors | per voice (see each voice's model card) |
| Gemma on-device models (LiteRT-LM) | Google | Gemma Terms of Use |
| Gemini API (cloud service, used with the user's own key) | Google | Gemini API Terms of Service |

**espeak-ng (GPL-3.0-or-later).** Some text-to-speech engines above (Piper, Kokoro's phonemizer) can use
espeak-ng for pronunciation. espeak-ng is not part of this repository and is not bundled with any Spike
build; where it is used, it is installed separately under its own GPL licence.

## 6. Excluded on purpose

Anything whose terms do not allow redistribution, or that belongs to someone else, is kept out of this
repository: third-party reference images, voice reference recordings, all model weights, the NuGet
command-line binary, and all built installers and packages.

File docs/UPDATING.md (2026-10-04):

# Updating the Spike website

The website is the `docs/` folder of this repository. GitHub Pages publishes it automatically at
<https://nur-arpon.github.io/Spike/> a minute or two after every push to `main`. There is no build step:
every file here is served exactly as it is.

| What | Where |
|---|---|
| Pages | `index.html` (Home), `meet-spike.html`, `robot.html`, `app.html`, `updates.html`, `privacy-policy.html`, `404.html` |
| Interactive 3D model (The Robot page) | `robot-3d.html`, made by `tools/make_robot_3d.py` |
| Design (colours, type, layout) | `assets/css/site.css` (one file; colour tokens at the top) |
| Behaviour | `assets/js/site.js` (menu, image switcher, screenshot tabs, 3D loader, reads the data files) |
| Names, links, statuses, robot build steps | `data/site.json` |
| Updates / changelog | `data/updates.json` |
| Images | `assets/img/` (`robot/`, `app/`, `cad/`, logo, icons, `og.png` for link previews) |
| Search engines | `sitemap.xml`, `robots.txt` |

## Post an update (the common case)

1. Open `data/updates.json`.
2. Copy an existing entry and paste it at the **top** of the `updates` list (newest first):

   ```json
   {
     "date": "2026-10-12",
     "tag": "Robot",
     "title": "The first print is done",
     "text": "One or two plain sentences about what changed and why it matters.",
     "link": "robot.html",
     "linkText": "See the robot"
   },
   ```

   - `date` is `YYYY-MM-DD`. The list is sorted by date anyway, so order mistakes are harmless.
   - `tag` is one word. The filter buttons on the Updates page are made from the tags in use, so a new tag
     (for example `Video`) gets its own button automatically. Current tags: App, Robot, Brain, Face, Design,
     Website.
   - `link` and `linkText` are optional. Use a page (`app.html`), a section (`robot.html#design`) or a full URL.
3. Commit and push. The newest three updates also appear on the Home page.

Check the file is still valid JSON (a missing comma breaks the list): paste it into any JSON validator, or
run `python -m json.tool docs/data/updates.json`.
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

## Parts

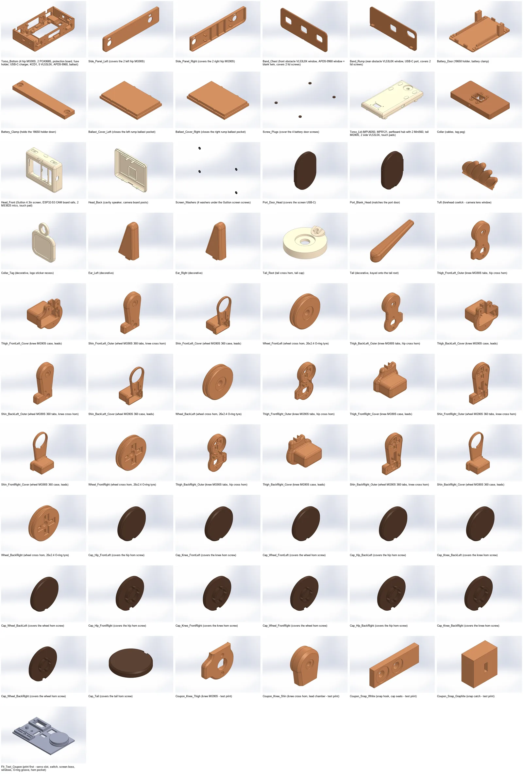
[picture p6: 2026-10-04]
docs/assets/img/cad/parts-sheet.webp

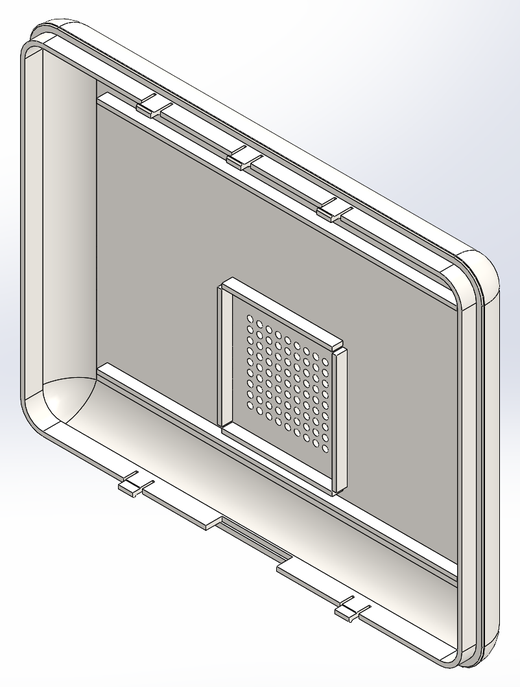
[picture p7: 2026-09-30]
guide/src/generated/parts/Head_Back.png

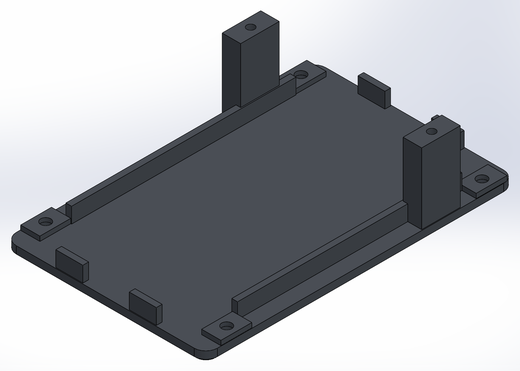
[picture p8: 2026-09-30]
guide/src/generated/parts/Battery_Door.png

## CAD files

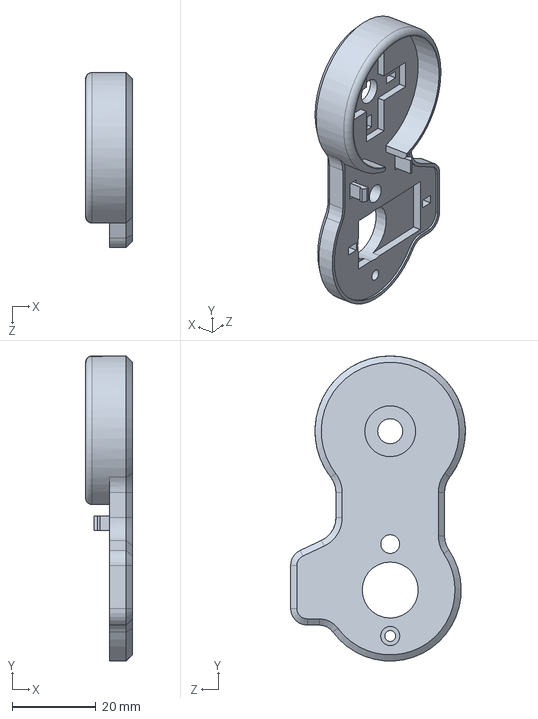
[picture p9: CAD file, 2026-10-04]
cad/print_v3_2/Thigh_FrontLeft_Outer (knee MG90S tabs, hip cross horn).SLDPRT
11.2 x 73.0 x 41.8 mm

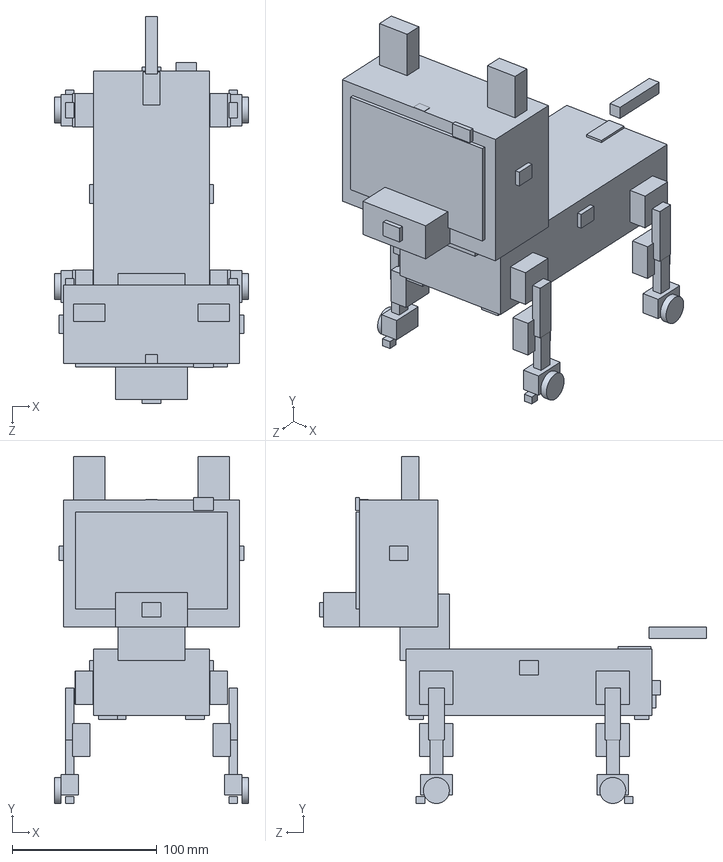
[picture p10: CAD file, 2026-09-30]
cad/RobotDog_v4_layout.SLDPRT
134.5 x 240.0 x 268.0 mm

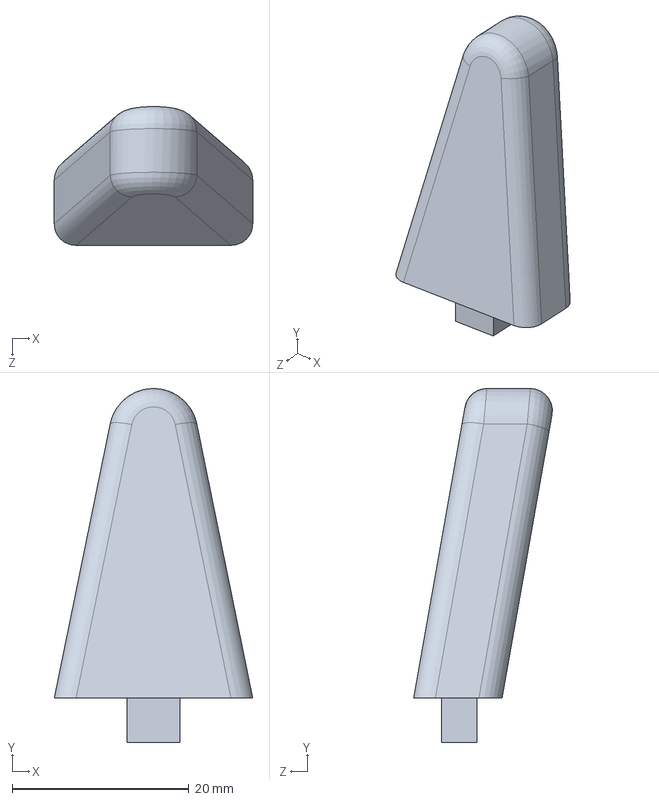
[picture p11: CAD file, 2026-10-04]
cad/print_v3_2/Ear_Left (decorative).SLDPRT
22.4 x 40.0 x 15.7 mm

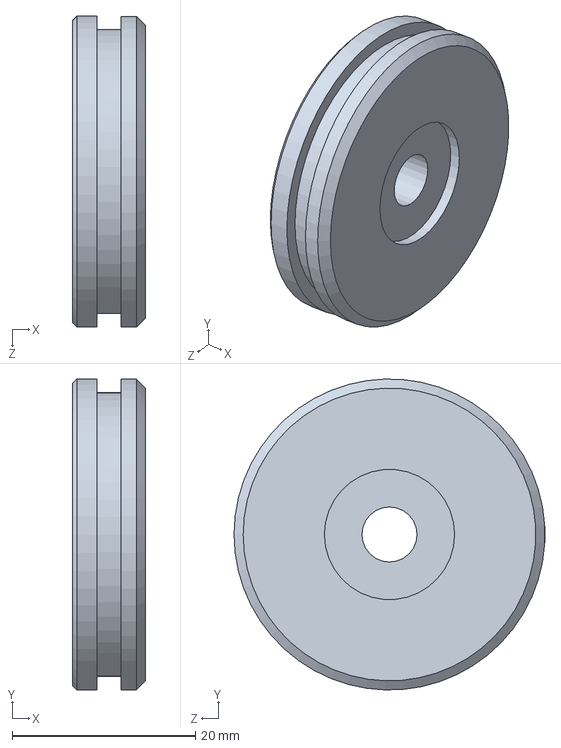
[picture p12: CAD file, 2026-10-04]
cad/print_v3_2/Wheel_FrontLeft (wheel cross horn, 26x2.4 O-ring tyre).SLDPRT
8.00 x 33.9 x 33.9 mm

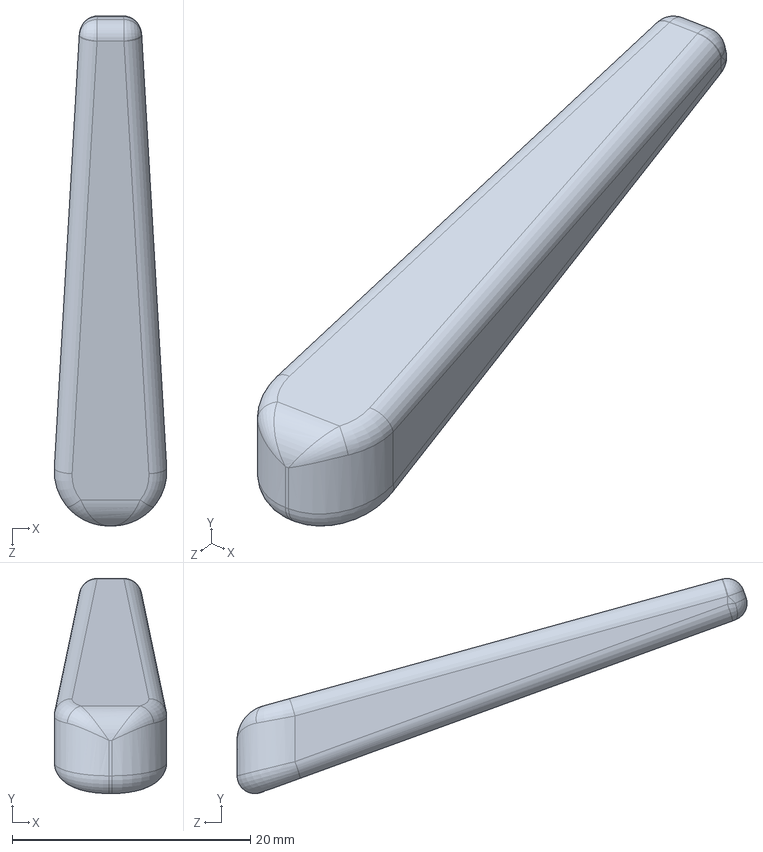
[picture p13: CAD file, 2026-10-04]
cad/print_v3_2/Tail (decorative, keyed onto the tail root).SLDPRT
9.44 x 18.1 x 42.8 mm

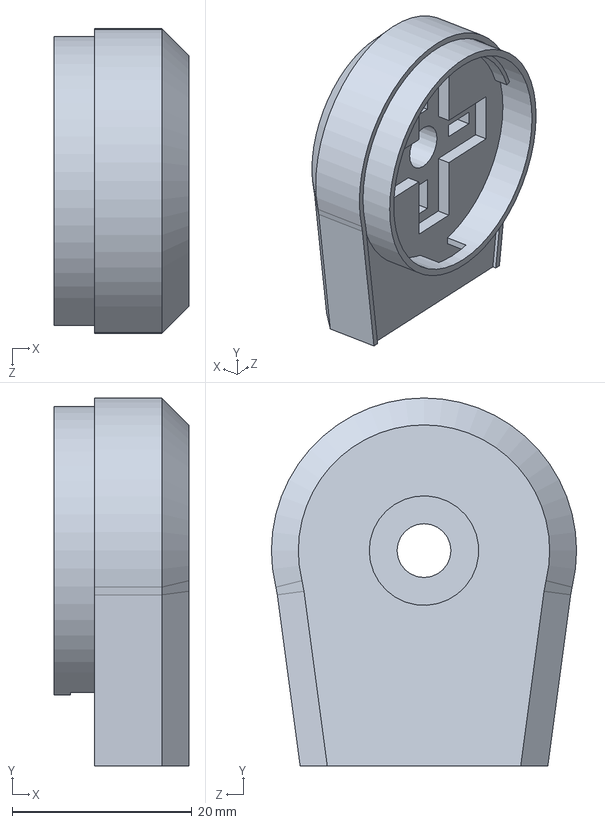
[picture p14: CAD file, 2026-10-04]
cad/print_v3_2/Coupon_Knee_Shin (knee cross horn, lead chamber - test print).SLDPRT
15.0 x 41.0 x 34.0 mm

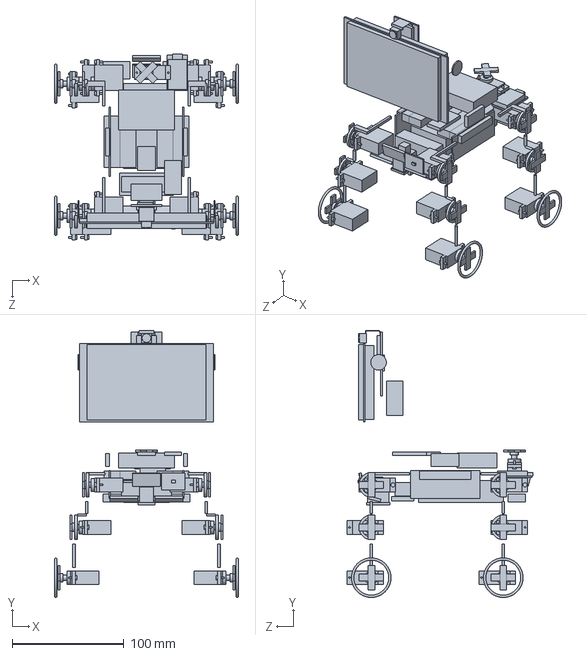
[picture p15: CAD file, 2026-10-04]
cad/print_v3_2/BOUGHT - every purchased part in place.SLDPRT
164.6 x 238.7 x 166.2 mm

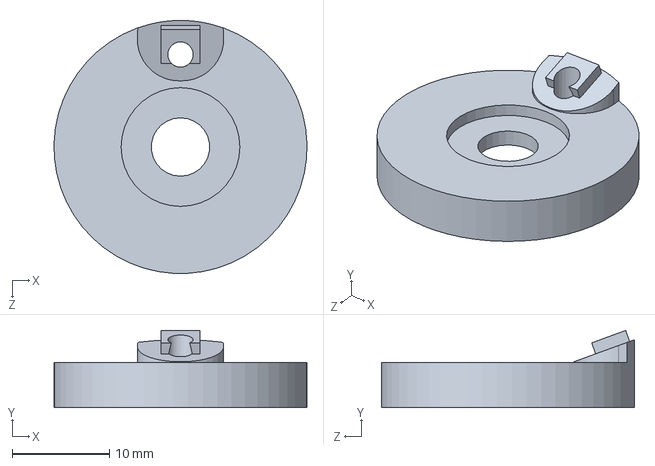
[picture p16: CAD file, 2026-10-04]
cad/print_v3_2/Tail_Root (tail cross horn, tail cap).SLDPRT
26.0 x 7.91 x 26.0 mm

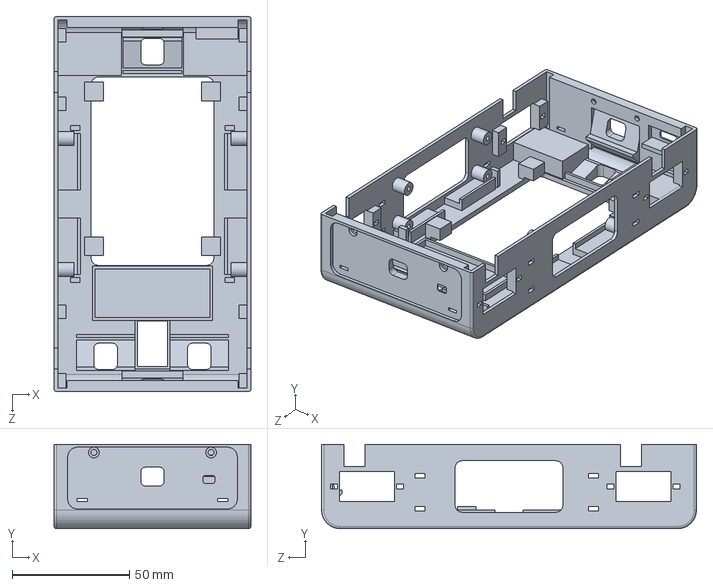
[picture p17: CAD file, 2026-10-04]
cad/print_v3_2/Torso_Bottom (4 hip MG90S, 2 PCA9685, protection board, fuse holder, USB-C charger, KCD1, 5 VL53L0X, APDS-9960, ballast).SLDPRT
84.0 x 36.0 x 160.0 mm

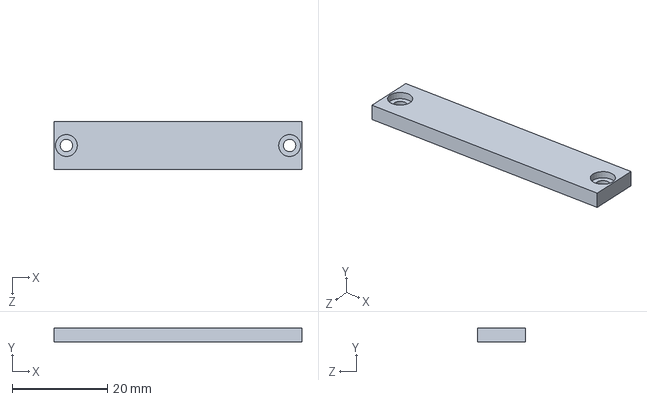
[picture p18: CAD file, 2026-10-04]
cad/print_v3_2/Battery_Clamp (holds the 18650 holder down).SLDPRT
52.0 x 3.00 x 10.0 mm

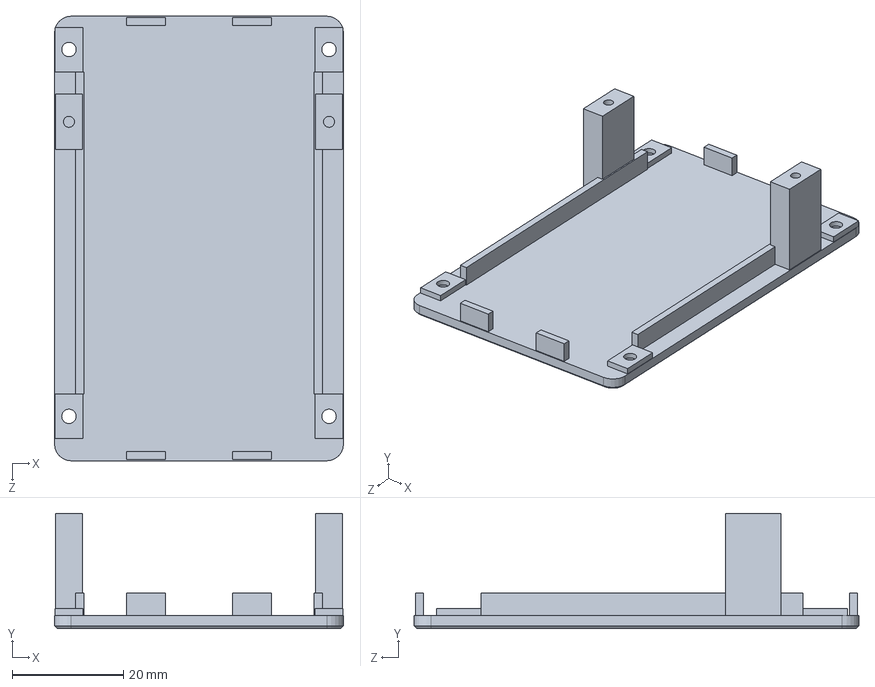
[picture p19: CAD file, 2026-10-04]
cad/print_v3_2/Battery_Door (18650 holder, battery clamp).SLDPRT
52.0 x 20.8 x 80.0 mm

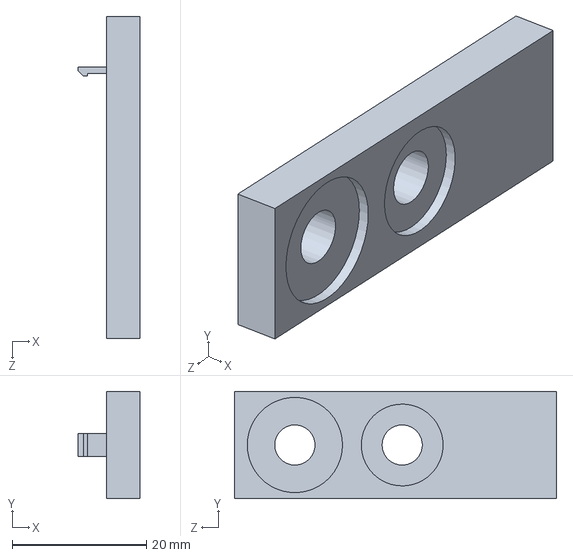
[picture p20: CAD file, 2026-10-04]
cad/print_v3_2/Coupon_Snap_White (snap hook, cap seats - test print).SLDPRT
9.20 x 16.0 x 48.0 mm

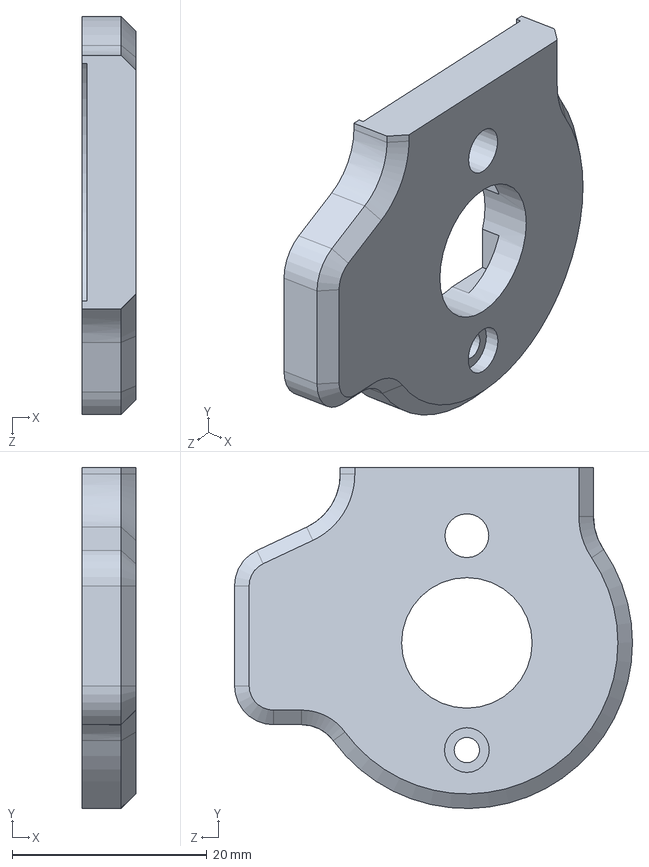
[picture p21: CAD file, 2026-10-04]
cad/print_v3_2/Coupon_Knee_Thigh (knee MG90S - test print).SLDPRT
5.50 x 35.0 x 40.8 mm

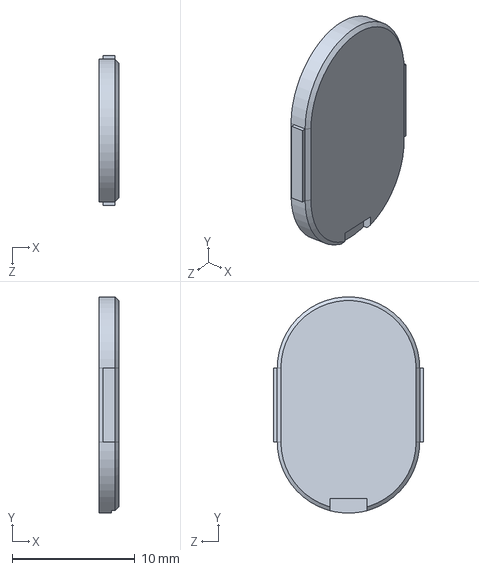
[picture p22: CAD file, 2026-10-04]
cad/print_v3_2/Port_Blank_Head (matches the port door).SLDPRT
1.60 x 17.6 x 12.2 mm

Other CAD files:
cad/print_v3_2/Desk Buddy v3.2 - full assembly.SLDASM
cad/print_v3_2/Thigh_BackRight_Outer (knee MG90S tabs, hip cross horn).SLDPRT
cad/print_v3_2/Ear_Right (decorative).SLDPRT
cad/print_v3_2/Tuft (forehead cowlick - camera lens window).SLDPRT
cad/print_v1/Ear.SLDPRT
cad/print_v1/Ear.STL
cad/print_v1/Head_Back.SLDPRT
cad/print_v1/Head_Back.STL
cad/print_v1/Head_Front.SLDPRT
cad/print_v1/Head_Front.STL
cad/print_v1/Leg_Shin_WheelFoot.SLDPRT
cad/print_v1/Leg_Shin_WheelFoot.STL
cad/print_v1/Leg_Thigh.SLDPRT
cad/print_v1/Leg_Thigh.STL
cad/print_v1/Muzzle.SLDPRT
cad/print_v1/Muzzle.STL
cad/print_v1/Neck.SLDPRT
cad/print_v1/Neck.STL
cad/print_v1/Tail.SLDPRT
cad/print_v1/Tail.STL
cad/print_v1/Torso_Bottom.SLDPRT
cad/print_v1/Torso_Bottom.STL
cad/print_v1/Torso_Lid.SLDPRT
cad/print_v1/Torso_Lid.STL
cad/print_v1/Wheel_30mm.SLDPRT
cad/print_v1/Wheel_30mm.STL
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

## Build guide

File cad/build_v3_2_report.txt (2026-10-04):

OK  Torso_Bottom              160.0 x  84.0 x  36.0 mm    68.7 g solid    56.1 g printed (fill 0.82, bed axis y; 2 walls 50.2 g)  bodies=1 STL shells=1  STL size+volume ok
OK  Side_Panel_Left           160.0 x  36.0 x   9.4 mm    17.0 g solid    15.7 g printed (fill 0.92, bed axis x; 2 walls 14.9 g)  bodies=1 STL shells=1  STL size+volume ok
OK  Side_Panel_Right          160.0 x  36.0 x   9.4 mm    17.0 g solid    15.7 g printed (fill 0.92, bed axis x; 2 walls 14.9 g)  bodies=1 STL shells=1  STL size+volume ok
OK  Band_Chest                 72.0 x  26.0 x   5.4 mm     3.2 g solid     3.2 g printed (fill 1.00, bed axis z; 2 walls 3.2 g)  bodies=1 STL shells=1  STL size+volume ok
OK  Band_Rump                  72.0 x  26.0 x   5.4 mm     3.4 g solid     3.4 g printed (fill 1.00, bed axis z; 2 walls 3.4 g)  bodies=1 STL shells=1  STL size+volume ok
OK  Battery_Door               80.0 x  52.0 x  20.8 mm    15.4 g solid    11.6 g printed (fill 0.76, bed axis y; 2 walls 11.1 g)  bodies=1 STL shells=1  STL size+volume ok
OK  Battery_Clamp              52.0 x  10.0 x   3.0 mm     1.9 g solid     1.4 g printed (fill 0.74, bed axis y; 2 walls 1.3 g)  bodies=1 STL shells=1  STL size+volume ok
OK  Ballast_Cover_Left         25.6 x  16.8 x   2.4 mm     1.2 g solid     0.9 g printed (fill 0.78, bed axis y; 2 walls 0.9 g)  bodies=1 STL shells=1  STL size+volume ok
OK  Ballast_Cover_Right        25.6 x  16.8 x   2.4 mm     1.2 g solid     0.9 g printed (fill 0.78, bed axis y; 2 walls 0.9 g)  bodies=1 STL shells=1  STL size+volume ok
OK  Screw_Plugs                70.1 x  50.9 x   1.0 mm     0.1 g solid     0.1 g printed (fill 1.00, bed axis y; 2 walls 0.1 g)  bodies=4 STL shells=4  STL size+volume ok
OK  Torso_Lid                 160.0 x  84.0 x  21.3 mm    59.8 g solid    48.9 g printed (fill 0.82, bed axis y; 2 walls 46.0 g)  bodies=1 STL shells=1  STL size+volume ok
OK  Collar                     84.0 x  46.9 x  11.5 mm    13.0 g solid    12.8 g printed (fill 0.99, bed axis y; 2 walls 12.4 g)  bodies=1 STL shells=1  STL size+volume ok
OK  Head_Front                126.0 x  98.3 x  33.5 mm    41.6 g solid    39.6 g printed (fill 0.95, bed axis z; 2 walls 37.9 g)  bodies=1 STL shells=1  STL size+volume ok
OK  Head_Back                 126.0 x  98.0 x  19.8 mm    33.3 g solid    32.6 g printed (fill 0.98, bed axis z; 2 walls 31.4 g)  bodies=1 STL shells=1  STL size+volume ok
OK  Screen_Washers            118.6 x  68.1 x   0.8 mm     0.1 g solid     0.1 g printed (fill 1.00, bed axis z; 2 walls 0.1 g)  bodies=4 STL shells=4  STL size+volume ok
OK  Port_Door_Head             17.6 x  12.2 x   1.6 mm     0.3 g solid     0.3 g printed (fill 1.00, bed axis x; 2 walls 0.3 g)  bodies=1 STL shells=1  STL size+volume ok
OK  Port_Blank_Head            17.6 x  12.2 x   1.6 mm     0.3 g solid     0.3 g printed (fill 1.00, bed axis x; 2 walls 0.3 g)  bodies=1 STL shells=1  STL size+volume ok
OK  Tuft                       25.6 x  15.2 x   7.2 mm     1.2 g solid     0.9 g printed (fill 0.74, bed axis y; 2 walls 0.7 g)  bodies=1 STL shells=1  STL size+volume ok
OK  Collar_Tag                 30.2 x  22.0 x   2.4 mm     1.2 g solid     1.1 g printed (fill 0.89, bed axis z; 2 walls 1.0 g)  bodies=1 STL shells=1  STL size+volume ok
OK  Ear_Left                   40.0 x  22.4 x  15.7 mm     6.4 g solid     3.2 g printed (fill 0.50, bed axis y; 2 walls 2.5 g)  bodies=1 STL shells=1  STL size+volume ok
OK  Ear_Right                  40.0 x  22.4 x  15.7 mm     6.4 g solid     3.2 g printed (fill 0.50, bed axis y; 2 walls 2.5 g)  bodies=1 STL shells=1  STL size+volume ok
OK  Tail_Root                  26.0 x  26.0 x   7.9 mm     2.2 g solid     1.7 g printed (fill 0.78, bed axis y; 2 walls 1.6 g)  bodies=1 STL shells=1  STL size+volume ok
OK  Tail                       42.8 x  18.1 x   9.5 mm     2.0 g solid     1.3 g printed (fill 0.62, bed axis y; 2 walls 1.1 g)  bodies=1 STL shells=1  STL size+volume ok
OK  Thigh_FrontLeft_Outer      73.0 x  41.8 x  11.2 mm    12.6 g solid     7.9 g printed (fill 0.63, bed axis x; 2 walls 7.3 g)  bodies=1 STL shells=1  STL size+volume ok
OK  Thigh_FrontLeft_Cover      40.8 x  40.5 x  28.2 mm    10.5 g solid     8.6 g printed (fill 0.81, bed axis x; 2 walls 7.2 g)  bodies=1 STL shells=1  STL size+volume ok
OK  Shin_FrontLeft_Outer       70.4 x  40.8 x  13.4 mm    21.0 g solid    10.6 g printed (fill 0.50, bed axis x; 2 walls 9.0 g)  bodies=1 STL shells=1  STL size+volume ok
OK  Shin_FrontLeft_Cover       70.4 x  40.8 x  28.2 mm    10.4 g solid     9.0 g printed (fill 0.86, bed axis x; 2 walls 8.0 g)  bodies=1 STL shells=1  STL size+volume ok
OK  Wheel_FrontLeft            33.9 x  33.9 x   8.0 mm     7.2 g solid     3.9 g printed (fill 0.54, bed axis x; 2 walls 3.5 g)  bodies=1 STL shells=1  STL size+volume ok
OK  Thigh_BackLeft_Outer       73.0 x  41.8 x  11.2 mm    12.6 g solid     7.9 g printed (fill 0.63, bed axis x; 2 walls 7.3 g)  bodies=1 STL shells=1  STL size+volume ok
OK  Thigh_BackLeft_Cover       40.8 x  40.5 x  28.2 mm    10.5 g solid     8.6 g printed (fill 0.82, bed axis x; 2 walls 7.2 g)  bodies=1 STL shells=1  STL size+volume ok
OK  Shin_BackLeft_Outer        70.4 x  40.8 x  13.4 mm    21.0 g solid    10.6 g printed (fill 0.50, bed axis x; 2 walls 9.0 g)  bodies=1 STL shells=1  STL size+volume ok
OK  Shin_BackLeft_Cover        70.4 x  40.9 x  28.2 mm    10.4 g solid     9.0 g printed (fill 0.86, bed axis x; 2 walls 8.0 g)  bodies=1 STL shells=1  STL size+volume ok
OK  Wheel_BackLeft             33.9 x  33.9 x   8.0 mm     7.2 g solid     3.9 g printed (fill 0.54, bed axis x; 2 walls 3.5 g)  bodies=1 STL shells=1  STL size+volume ok
OK  Thigh_FrontRight_Outer     73.0 x  41.8 x  11.2 mm    12.6 g solid     7.9 g printed (fill 0.63, bed axis x; 2 walls 7.3 g)  bodies=1 STL shells=1  STL size+volume ok
OK  Thigh_FrontRight_Cover     40.8 x  40.5 x  28.2 mm    10.5 g solid     8.6 g printed (fill 0.82, bed axis x; 2 walls 7.2 g)  bodies=1 STL shells=1  STL size+volume ok
OK  Shin_FrontRight_Outer      70.4 x  40.8 x  13.4 mm    21.0 g solid    10.5 g printed (fill 0.50, bed axis x; 2 walls 9.0 g)  bodies=1 STL shells=1  STL size+volume ok
OK  Shin_FrontRight_Cover      70.4 x  40.8 x  28.2 mm    10.4 g solid     9.0 g printed (fill 0.87, bed axis x; 2 walls 8.0 g)  bodies=1 STL shells=1  STL size+volume ok
OK  Wheel_FrontRight           33.9 x  33.9 x   8.0 mm     7.2 g solid     3.9 g printed (fill 0.54, bed axis x; 2 walls 3.5 g)  bodies=1 STL shells=1  STL size+volume ok
OK  Thigh_BackRight_Outer      73.0 x  41.8 x  11.2 mm    12.6 g solid     7.9 g printed (fill 0.63, bed axis x; 2 walls 7.3 g)  bodies=1 STL shells=1  STL size+volume ok
OK  Thigh_BackRight_Cover      40.8 x  40.5 x  28.2 mm    10.5 g solid     8.6 g printed (fill 0.82, bed axis x; 2 walls 7.2 g)  bodies=1 STL shells=1  STL size+volume ok
OK  Shin_BackRight_Outer       70.4 x  40.8 x  13.4 mm    21.0 g solid    10.5 g printed (fill 0.50, bed axis x; 2 walls 9.0 g)  bodies=1 STL shells=1  STL size+volume ok
OK  Shin_BackRight_Cover       70.4 x  40.9 x  28.2 mm    10.4 g solid     9.0 g printed (fill 0.87, bed axis x; 2 walls 8.0 g)  bodies=1 STL shells=1  STL size+volume ok
OK  Wheel_BackRight            33.9 x  33.9 x   8.0 mm     7.2 g solid     3.9 g printed (fill 0.54, bed axis x; 2 walls 3.5 g)  bodies=1 STL shells=1  STL size+volume ok
OK  Cap_Hip_FrontLeft          12.0 x  11.9 x   2.8 mm     0.2 g solid     0.2 g printed (fill 0.97, bed axis x; 2 walls 0.2 g)  bodies=1 STL shells=1  STL size+volume ok
OK  Cap_Knee_FrontLeft         12.0 x  11.9 x   2.8 mm     0.2 g solid     0.2 g printed (fill 0.97, bed axis x; 2 walls 0.2 g)  bodies=1 STL shells=1  STL size+volume ok
OK  Cap_Wheel_FrontLeft        14.0 x  14.0 x   2.8 mm     0.3 g solid     0.3 g printed (fill 0.97, bed axis x; 2 walls 0.3 g)  bodies=1 STL shells=1  STL size+volume ok
OK  Cap_Hip_BackLeft           12.0 x  11.9 x   2.8 mm     0.2 g solid     0.2 g printed (fill 0.97, bed axis x; 2 walls 0.2 g)  bodies=1 STL shells=1  STL size+volume ok
OK  Cap_Knee_BackLeft          12.0 x  11.9 x   2.8 mm     0.2 g solid     0.2 g printed (fill 0.97, bed axis x; 2 walls 0.2 g)  bodies=1 STL shells=1  STL size+volume ok
OK  Cap_Wheel_BackLeft         14.0 x  14.0 x   2.8 mm     0.3 g solid     0.3 g printed (fill 0.97, bed axis x; 2 walls 0.3 g)  bodies=1 STL shells=1  STL size+volume ok
OK  Cap_Hip_FrontRight         12.0 x  11.9 x   2.8 mm     0.2 g solid     0.2 g printed (fill 0.97, bed axis x; 2 walls 0.2 g)  bodies=1 STL shells=1  STL size+volume ok
OK  Cap_Knee_FrontRight        12.0 x  11.9 x   2.8 mm     0.2 g solid     0.2 g printed (fill 0.97, bed axis x; 2 walls 0.2 g)  bodies=1 STL shells=1  STL size+volume ok
OK  Cap_Wheel_FrontRight       14.0 x  14.0 x   2.8 mm     0.3 g solid     0.3 g printed (fill 0.98, bed axis x; 2 walls 0.3 g)  bodies=1 STL shells=1  STL size+volume ok
OK  Cap_Hip_BackRight          12.0 x  11.9 x   2.8 mm     0.2 g solid     0.2 g printed (fill 0.97, bed axis x; 2 walls 0.2 g)  bodies=1 STL shells=1  STL size+volume ok
OK  Cap_Knee_BackRight         12.0 x  11.9 x   2.8 mm     0.2 g solid     0.2 g printed (fill 0.97, bed axis x; 2 walls 0.2 g)  bodies=1 STL shells=1  STL size+volume ok
OK  Cap_Wheel_BackRight        14.0 x  14.0 x   2.8 mm     0.3 g solid     0.3 g printed (fill 0.98, bed axis x; 2 walls 0.3 g)  bodies=1 STL shells=1  STL size+volume ok
OK  Cap_Tail                   12.0 x  11.9 x   2.6 mm     0.2 g solid     0.2 g printed (fill 0.97, bed axis y; 2 walls 0.2 g)  bodies=1 STL shells=1  STL size+volume ok
OK  Coupon_Knee_Thigh          40.8 x  35.0 x   5.5 mm     5.4 g solid     3.4 g printed (fill 0.62, bed axis x; 2 walls 3.0 g)  bodies=1 STL shells=1  STL size+volume ok
OK  Coupon_Knee_Shin           41.0 x  34.0 x  15.0 mm    13.6 g solid     6.5 g printed (fill 0.47, bed axis x; 2 walls 5.6 g)  bodies=1 STL shells=1  STL size+volume ok
OK  Coupon_Snap_White          48.0 x  16.0 x   9.2 mm     4.1 g solid     2.6 g printed (fill 0.64, bed axis x; 2 walls 2.3 g)  bodies=1 STL shells=1  STL size+volume ok
OK  Coupon_Snap_Graphite       12.0 x  12.0 x   6.2 mm     1.1 g solid     0.7 g printed (fill 0.69, bed axis x; 2 walls 0.6 g)  bodies=1 STL shells=1  STL size+volume ok
OK  Fit_Test_Coupon            95.0 x  60.0 x  10.4 mm    27.4 g solid    16.0 g printed (fill 0.58, bed axis y; 2 walls 14.8 g)  bodies=1 STL shells=1  STL size+volume ok
    printed total 547 g solid, 418 g as printed (robot parts only; sliced from the exported STLs: 3 walls x 0.4 mm, 0.8 mm top/bottom, 15 % gyroid, 0.2 mm layers; overall fill 0.764)
    with 2 walls instead: 382 g as printed
SLICER PROFILE (grams as printed, all 55 robot parts, from the exported STLs):
  3 walls everywhere: 417.8 g | 2 walls everywhere: 381.7 g | 2 walls + 3 walls on the 8 leg outer halves: 390.3 g
  CHOSEN: 2 walls for every part -> 381.7 g (limit 400 g); 0.8 mm top/bottom, 15 % gyroid, 0.2 mm layers, 0.4 mm lines. Skirts, brims and supports come on top (about 1-3 %).
OK  BOUGHT - every purchased part in place  bodies=235
CLASH CHECK: 297 bodies, 0 clashes
BALANCE: total 1025 g, centre of mass x +0.3  y 25.6 (108 mm above the desk)  z +12.4 mm (feet at z +66 / -52)
  on 4 wheels: 53.6 mm inside the support area
  lift front left  foot:   -4.5 mm
  lift front right foot:   -4.2 mm
  lift rear right  foot:   +4.5 mm
  lift rear left   foot:   +4.2 mm
  WITHOUT the 2 ballast slugs:
  BALANCE: total 981 g, centre of mass x +0.3  y 26.5 (109 mm above the desk)  z +15.8 mm (feet at z +66 / -52)
    on 4 wheels: 50.2 mm inside the support area
    lift front left  foot:   -7.3 mm
    lift front right foot:   -7.0 mm
    lift rear right  foot:   +7.3 mm
    lift rear left   foot:   +7.0 mm
  v2 for comparison: total 840 g, centre of mass z +17.4, on 4 wheels 48.6 mm inside, lift front left/right -8.3 / -8.5 mm
  v3 for comparison: total 1058 g, centre of mass z +17.0, on 4 wheels 49.0 mm inside, lift front left/right -8.2 / -8.0 mm, lift rear right/left +8.2 / +8.0 mm (printed parts at FILL 0.75 = 460 g)
  v3 measured the same way as v3.1 (its own STLs through the same slicer model, 2 walls = 393 g, same bought parts): total 991 g, centre of mass z +17.4, on 4 wheels 48.6 mm inside, lift front left/right -8.5 / -8.3 mm, lift rear right/left +8.5 / +8.3 mm (with 3 walls: 48.3 mm). FILL 0.75 on every part over-weighted the legs (they print at 50-60 % fill), which put the v3 report's centre of mass 0.4 mm too far back.
  v3.1 report for comparison: total 983 g, centre of mass x +0.2 y 25.5 (107 mm above the desk) z +17.2, on 4 wheels 48.8 mm inside, lift front left/right -8.4 / -8.2 mm, lift rear right/left +8.4 / +8.2 mm
ASSEMBLY: 57 of 57 files inserted, each checked to sit at its modelled position (inside picture: 45 shells made see-through; GDI objects at the end 1893)
SECTION PICTURES (exploded; labels anchored on each part's own pixels):
  section 1 Body: "ballast steel slug (x2) (bought)" not visible in this view (0 px) - no label
  section 1 Body: 17 labels -> Desk Buddy v3.2 - full assembly - section 1 Body (exploded, labelled).png
  section 2 Lid: 9 labels -> Desk Buddy v3.2 - full assembly - section 2 Lid (exploded, labelled).png
  section 3 Head: 15 labels -> Desk Buddy v3.2 - full assembly - section 3 Head (exploded, labelled).png
  section 4 Leg: 12 labels -> Desk Buddy v3.2 - full assembly - section 4 Leg (exploded, labelled).png
LEG CLEARANCE SWEEPS (side view, from the build outlines):
  knee pod front vs belly (pod): min  3.54 mm over hip +/-30 deg (at -30.0 deg, z +43.1); first touch at none / -38.5 deg
  knee pod front vs belly (pod + root fillet under the panel): min  2.87 mm over hip +/-30 deg (at -30.0 deg, z +43.1); first touch at none / -37.0 deg
  knee pod rear  vs belly (pod): min  3.39 mm over hip +/-30 deg (at -30.0 deg, z -76.0); first touch at 38.5 / -48.5 deg
  knee pod rear  vs belly (pod + root fillet under the panel): min  2.62 mm over hip +/-30 deg (at -30.0 deg, z -76.0); first touch at 37.0 / -43.0 deg
  paw band (toe/heel, R4) vs desk (y -82.7): min 5.95 mm over shin tilt -9.9..+19.8 deg (at -9.9)
  paw pod (R4 lower corners) vs desk (y -82.7): min 6.41 mm over shin tilt -9.9..+19.8 deg (at -9.9)
  paw front vs belly: min 44.9 mm with the shin inside the gait limits; 9.0 mm over the full hip +/-30 x knee +/-50 deg (at hip -30, knee -50)
  paw rear  vs belly: min 43.4 mm with the shin inside the gait limits; -1.6 mm over the full hip +/-30 x knee +/-50 deg (at hip +30, knee +50)
  paw vs thigh + knee pod over knee +/-50 deg: min distance 14.6 mm
  lead corridors (gap for a dia 2.4 bundle): knee 3.48 mm, paw 2.79 mm
JOINT LIMITS for the firmware (paw pod >= 2.0 mm under the belly; + = foot forward, - = foot back; servo range assumed +/-50):
  front legs: paw pod vs belly 11.5 mm at worst (hip -30, knee -50); the v3 whole-paw outline gives 9.0 mm (it counts the toe, which is outboard of the body)
  front legs: no limit needed inside hip +/-30 x knee +/-50
  rear legs : paw pod vs belly 0.9 mm at worst (hip +30, knee +50); the v3 whole-paw outline gives -1.6 mm (it counts the toe, which is outboard of the body)
  rear legs : hip +29: knee -50..+49; hip +30: knee -50..+48
  rear legs : SIMPLE RULE: when hip >= +29 deg, keep knee <= +48 deg
  gait limits (shin tilt = hip + knee between -9.9 and +19.8 deg) never reach these limits
BODY (v3 sections 2-7):
  lower body width 97.2 (side panels), belly R8 at chest and rump, lid top R6, head R8 face / R10 back / R8 side edges
  hip leads: panel slot 9 x 5 at y 26.5-31.5, tub-wall notch 9 wide from y 26.5 to the rim, lid comb teeth down to y 29.0
  USB-C: 13 x 7 pill in the rump band at x 27.5, y 27.58; receptacle face 1.5 behind the band face; charger raised to y 24.35
  KCD1 at the front belly centre, z 50.0-69.4, flush in a 2.2 recess; battery door x +-26, z -54..26
  tail: servo under the lid (tabs at y 33.6), root dia 26 in a dia 27.6 socket, tail rises 20 deg
v3.2 CHANGES:
  one face: muzzle, its port door + blank and the 4 face screws removed; the face below the screen is plain shell
  forehead camera: OV5640 lens centred at y 149.25 (brow, 5.8 above the screen glass), behind a dia 6.2 hole (0.6 chamfer) just under the tuft; module 8.5 sq x 6.9 deep in a collar inside the head front, lens 1.0 behind the wall (no notch needed); tuft kept out of a 70 deg cone
  camera flex route: module top edge -> up to y 155.8 -> back under the roof to z 58.5 -> down into the board connector: 16.5 mm of path + ~3 mm in the connector = needs >= 19 mm of flex from the module edge (MEASURE the delivered module; firmware turns the image 180 deg: vflip + hmirror)
  ESP32-S3 CAM board: upright in 2 rails behind the screen, |x| <= 14.0, y 97.5-154.5, PCB z 56.0-57.6 (screen back parts start at z 63.5); USB-C end down, reached with the head back off (no pin headers)
  APDS-9960 (GY-9960-3.3, 21 x 15.5): behind the CHEST band at x +24.1 (the robot left side), chip face 77.8 behind a 0.6 skin with a 5 x 3.4 aperture, looking out through a 10 x 8 window matching the laser window; a blank twin window at x -24.1. (In the tuft it needed a 31 x 35 mm slab: the board is 21 x 15.5.)
  tuft (Plush, preview v7.1): caramel, 5 plump locks (sphere chains, dia >= 2.2 at the tips) on a 1.6 base plate on a flat 45 deg seat cut 0.4 into the head R8 round; x -12.2..13.4, top at y 168.6 (10.6 above the head top, 15.5 tall; the ears reach 192); glued on the seat, 2 dia 2 locating pins at x +-9.0, z 77.4; head openings under it |x| <= 4.2 (y >= 151.0, the notch above the lens) and 5.6 (y >= 153.8)
  touch pad moved to z 53.3 (v3.1 58); centre top head-back hook moved to x -12; 2 head-back posts hold the CAM board
  collar tag: 22 x 21 R5, keyhole on a dia 3.4 peg (head dia 4.8) at y 56.0; bottom 29.0 vs the chest laser window top 26.25
  paw pods: 3.5 x 45 deg inboard lower chamfer (lead gap filled, 1.6 wall); tyre groove r 15.5 (v3.1 13.9) with the SAME 26 x 2.4 O-ring: stretch 19.2 % (v3.1 6.9 %), tyre r 17.7 (v3.1 16.3), desk y -82.7
  ballast: 2 pockets x 24.8 x 16.0 x 7.7 (x, z, height) at |x| 14.4-39.2, z -72.0..-56.0; steel slug 24.0 x 7.5 x 15.8 = 22.3 g each. Coins do not fit: the largest free round is 16 mm (AU 5c = 19.4, $2 = 20.5, 20c = 28.65)
DESK-EDGE LASERS (front pair; reading along the beam to a flat desk, pitched nose-up about the rear wheels; edge alarm 110 mm):
  v3.2 (15 deg ahead of straight down, tyre r 17.7): chip 87.0 mm above the desk, spot 23 mm ahead of the chip; +0.0 deg 90 mm, +3.5 deg 99 mm, +8.0 deg 111 mm, +12.0 deg 122 mm
  v3.1 (25 deg, tyre r 16.3): chip 86.5 mm above the desk, spot 40 mm ahead of the chip; +0.0 deg 95 mm, +3.5 deg 106 mm, +8.0 deg 121 mm, +12.0 deg 136 mm
  v3.2 edge spot 21 mm ahead of the front wheel contacts (stopping from the 60 mm/s glide at 0.24 m/s2 takes ~8 mm + one 33 ms reading)
v3.1 CHANGES (all inside the parts; outside surfaces as v3):
  walls: head 1.6 (face 2.4 round the screen), tub sides/ends 1.6 (floor 2.4), lid walls 1.6 above a 1.8 lip (top 2.4), muzzle sides/top 1.8, collar 1.6; side panels as v3 (1.8 skin); tub side windows |z| <= 23, y 7-29 behind the panels
  balance: perfboard hub (22 g) moved 9 mm rearward under the lid (fences and tie anchors with it)
  tail cap: peg 1.0 long, its bottom at y 49.6 vs the tail horn top at y 49.0: 0.6 mm clear (v3 report: 1.9 mm3 overlap from an older run)
  head: collar screws on 0.8 pads (2.4 clamped, no counterbores), head-back lip notched |x| <= 9.8 over them; muzzle screws on 0.8 pads; screen frame plate 0.8; ears on 1.4 pads; snap detent pockets 0.4 deep (1.2 skin behind them - the one place under 1.6)
  battery door lugs 9.4 high (v3 8.6) so the door takes M2 x 6; touch-pad screws M2 x 4 (the v3 note said M2 x 6, which would pierce the lid top)
  ribs: 2 stiffening ribs 1.2 x 3 inside the head back at y 75 and 140 (the widest thin flat panel); the lid top keeps its 2.4 plate and ceiling fences, the side panels their 3 ribs

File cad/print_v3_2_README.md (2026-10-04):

# Desk Buddy - print model v3.2 (1 Oct 2026)

v3.2 is v3.1 with the face, camera and colour decisions of 29 Sep - 1 Oct built in, plus the walking fixes
the stability reviews asked for. Everything is made and checked by `build_print_parts_v3_2.py` (SolidWorks,
driven from Python, helpers in `swlib_v3_2.py`); the raw numbers are in `build_v3_2_report.txt`. v1, v2, v3
and v3.1 files are untouched. For everything not listed here (servo measurements to take, screws, joint
limits, assembly order) the v3.1 README still applies - `print_v3_1_README.md`.

| Folder / file | What is in it |
|---|---|
| `print_v3_2\` | SolidWorks files only: 56 robot parts, 5 test prints, the bought-parts model, `Desk Buddy v3.2 - full assembly.SLDASM` |
| `print_v3_2_stl\` | one STL per printed part (each checked after export: size, volume, 1 piece, fits the 223 x 220 x 205 bed) |
| `print_v3_2_png\` | a picture of every part; iso / front / side / top / back / under / inside; tuft close-ups (front, 3/4, side); head "section" (shells see-through, side and 3/4); 4 exploded + labelled section pictures |
| `build_v3_2_report.txt` | every check with its numbers |

## What changed from v3.1

1. **One face.** The muzzle, its port door and blank, and the 4 face screws are gone. The screen draws the nose
   and mouth. The face below the screen is plain 1.6 mm shell (no holes, no pads).
2. **Forehead camera under a tuft (owner decision 1 Oct; style "Plush" from 3D preview v7.1).** The OV5640 lens
   sits centred on the brow, 5.8 mm above the screen glass, behind a 6.2 mm hole (0.6 mm chamfer) just under **Spike's signature cowlick**: a caramel `Tuft` of 5 short, plump, rounded locks that grow from one
   thin base, all lean toward the robot's left and sweep back. It is 15.5 mm tall (10.6 mm above the head top;
   the ears are 34 mm) and 25.6 mm wide, 0.9 g. Nothing of the tuft enters a 70 deg cone above the lens.
   - The tuft's thin base sits on a small flat 45 deg seat (x +-11.2) cut 0.4 mm into the head's top-front round,
     located by 2 dia 2 pins in 2 holes and **glued** (CA or 2-part epoxy). A screw could not get enough thread
     in 1 g of plush locks, and the screw lands showed below the tuft - so no screws here.
   - The module sits between two guides inside the head front (a dot of glue fixes it), its lens 1.0 mm behind
     the wall, so the barrel clears the head's top round and only a dark dot shows. Beyond the seat the tuft's
     underside follows the head's round exactly.
   - **Colour:** print it in caramel. The preview's cream-to-caramel gradient cannot be printed on a single-
     nozzle printer. (Plush or Flick, and the final colour, are still open; v3.2 is built as Plush.)
   - **Print:** on its flat base (the seat face) on the bed; the locks rise at 50 deg or less, so at most the
     curled tips want a touch of tree support. Locks are 2.2 mm or thicker everywhere.
   - The ears are the plain v3.1 ears (no sensors, no inner triangles).
3. **Camera board inside the head.** The ESP32-S3 CAM board stands upright behind the screen in two rails
   (head front, floor to roof); two posts on the head back press its top against the rails when the head back
   clips on. Its USB-C end points down; flash it with the head back off. **No pin headers on this board.**
   The flex runs from the module's top edge back under the roof and down into the board's connector
   (16.5 mm of path, so the flex must be about **19 mm or longer** from the module edge - measure yours).
   Mounted this way the image is upside down: the camera firmware must set `vflip` and `hmirror`.
4. **Gesture sensor (APDS-9960) moved to the chest.** Inside the tuft it needed a 31 x 35 mm slab (the board is
   21 x 15.5 mm), which made the tuft a lump, not a cowlick. It now sits in a pocket in the chest wall behind
   the chest band, at x +24 (robot's left), looking forward through a 10 x 8 window identical to the obstacle
   laser's. A blank twin window on the right keeps the band symmetric (three matching windows). In front of the
   chip there is a 0.6 mm skin with a 5 x 3.4 mm slot, so the window shows plain wall + a small dark slot. Hands
   waving 5-20 cm in front of Spike are in its field; the desk is below it. Its lead now stays inside the body.
5. **Collar tag.** A 22 x 21 mm cream tag hangs from a peg on the collar front (keyhole: lift, hook over the peg
   head, let it drop). The face has a 17 x 16 x 0.6 mm recess for the logo sticker or a printed insert.
   Decorative only; its bottom is 2.75 mm above the chest laser window.
6. **Paw pods clear the desk in the tilt poses.** Two changes:
   - a 3.5 x 45 deg chamfer on each paw pod's inboard lower edge (the lead gap behind it is filled so the wall
     stays 1.6 mm, 0.6 mm clear of the wheel servo's case corner);
   - a **bigger tyre with the same O-ring**: the wheel groove is r 15.5 (was 13.9), so the 26 x 2.4 O-ring is
     stretched 19 % (was 7 %; O-ring drive belts run at 10-25 %) and the tyre radius is 17.7 (was 16.3). The
     wheels are 33.9 mm across (were 30.7). This lifts the whole robot 1.4 mm. Why both: the chamfer alone gains
     only ~0.1-0.5 mm, because the wheel servo's case corner (with its minimum wall) is what meets the desk.
     Details in "Clearances".
7. **Desk-edge lasers look 15 deg ahead of straight down** (was 25). A level desk now reads about 90 mm (was 95)
   and 99 mm at the gait's +3.5 deg nose-up (was 106), so the 110 mm edge alarm is no longer 4-5 mm away. The
   edge spot is still 21 mm ahead of the front wheels (glide stopping distance ~8 mm).
8. **Rump ballast pockets.** Two closed pockets in the tub floor under the rear hip servos, closed by flush
   caramel `Ballast_Cover_Left/Right` (press fit, pry notch) in the belly. **Coins do not fit anywhere at the
   rump:** the largest free round is 16 mm (AU 5c is 19.4, $2 is 20.5, 20c is 28.65). Each pocket takes a steel
   slug 24 x 7.5 x 15.8 mm = 22.3 g (cut from 25 x 8 mm flat bar, or stack 3 x 2.5 mm plates), 44.6 g for both.
   Lead shot or fishing sinkers also work (~30 g per pocket).
9. **Caramel Pup colours** as SolidWorks appearances (see "Filament colours").
10. Smaller items: the head touch pad moved 4.7 mm back (z 53.3) so the camera flex passes in front of it; the
    centre top snap hook of the head back moved to x -12 (it was under the new touch-pad boss).

## Files to ignore
`Tuft_Mask (...)` files in `print_v3_2\`, `print_v3_2_stl\` and `print_v3_2_png\` are left over from an earlier
v3.2 tuft design (a separate dark mask part). The final design has no mask; they are not in the assembly. Do not
print them (files are never deleted here - remove them yourself if you like).

## Filament colours (Caramel Pup) and slicer settings
Slicer settings are exactly the v3.1 ones (2 walls, 0.8 top/bottom, 15 % gyroid, 0.2 mm layers) - see the v3.1
README. **Robot total 381.7 g as printed** (v3.1: 385.7 g; the muzzle went, the tuft, tag and ballast covers came).

| Colour | Hex | Parts |
|---|---|---|
| cream | #F1DEC2 | Torso_Lid, Head_Front, Head_Back, Tail_Root, Collar_Tag |
| caramel | #B97A4F | Torso_Bottom, Side_Panel x2, Battery_Door, Battery_Clamp, Ballast_Cover x2, every Thigh/Shin outer half and cover, Wheel x4, Ear x2, Tuft, Tail |
| band brown | #A56A43 | Band_Chest, Band_Rump, Collar |
| cocoa | #4A3326 | the 13 hub caps, Port_Door_Head, Port_Blank_Head, Screw_Plugs, Screen_Washers (hidden - any dark filament) |

Ask Deer Park which cream / caramel / brown / dark-brown PLA they stock before the first print; the tuft is one
flat colour (caramel), not the preview's gradient.

## Print jobs and cost (Deer Park bands: $1 <= 10 g, $2 <= 20 g, $4 <= 40 g, $6 <= 60 g; or $1.10 per 10 g)
| Plate | Filament | Parts | g | Band | per 10 g |
|---|---|---|---:|---:|---:|
| T1 (first) | any | Fit_Test_Coupon, Coupon_Knee_Thigh, Coupon_Knee_Shin, Coupon_Snap_White, Coupon_Snap_Graphite | 26.3 | $4 | $2.89 |
| C1 | caramel | Torso_Bottom, Ballast_Cover x2, Battery_Clamp, Tail, Tuft | 55.1 | $6 | $6.06 |
| C2 | caramel | Side_Panel x2, Battery_Door, Ear x2 | 45.9 | $6 | $5.05 |
| C3 | caramel | Thigh outer x4, Thigh cover x4 | 58.0 | $6 | $6.38 |
| C4 | caramel | Shin outer x4, Wheel x4 | 50.0 | $6 | $5.50 |
| C5 | caramel | Shin cover x4 | 32.0 | $4 | $3.52 |
| K1 | cream | Torso_Lid, Tail_Root, Collar_Tag | 48.6 | $6 | $5.35 |
| K2 | cream | Head_Front | 37.9 | $4 | $4.17 |
| K3 | cream | Head_Back | 31.4 | $4 | $3.45 |
| B1 | band brown | Collar, Band_Chest, Band_Rump | 19.0 | $2 | $2.09 |
| D1 | cocoa | 13 caps, 2 port door/blank, screw plugs, screen washers | 3.8 | $1 | $0.42 |
| **Robot** | | 56 files | **381.7** | **$45** | **$41.99** |

New print notes: `Tuft` - flat base (its 45 deg seat face) on the bed; at most a touch of tree support under
the curled tips. `Collar_Tag` - back face down. `Ballast_Cover` - outer (lip) face down. The wheels are now
dia 33.9 (fit-test the groove on the `Fit_Test_Coupon` first: the O-ring should need a firm stretch and sit
without twisting).

## Checks (from `build_v3_2_report.txt`, all on the EXPORTED files)
- 61 printed parts (56 robot + 5 test prints) built, 1 piece each in the model and in the STL, STL size and volume = model, all fit the bed.
- **0 clashes** over 297 bodies (printed vs printed, printed vs bought, bought vs bought).
- Assembly: 57 of 57 files at their modelled positions.

## Mass and centre of mass
| | total | CoM x / y (height above desk) / z | on 4 wheels | lift front L / R | lift rear R / L |
|---|---:|---|---:|---:|---:|
| v3.1 | 983 g | +0.2 / 25.5 (107) / +17.2 | 48.8 mm | -8.4 / -8.2 | +8.4 / +8.2 |
| v3.2 without ballast | 981 g | +0.3 / 26.5 (109) / +15.8 | 50.2 mm | -7.3 / -7.0 | +7.3 / +7.0 |
| **v3.2 with 2 slugs (44.6 g)** | **1025 g** | +0.3 / 25.6 (108) / **+12.4** | **53.6 mm** | **-4.5 / -4.2** | +4.5 / +4.2 |

The head change alone moves the weight 1.4 mm back; the slugs another 3.4 mm (4.8 mm total, the stability
research asked for ~5). The body sits 1.4 mm higher (bigger tyres).

## Servo loads and stability (re-run; outputs in `v3_2_servo_load_check_output.txt`, `v3_2_stability_check_output.txt`)
- `servo_load_check_v3_2.py`: worst case is still the instant wheel stop (skid), hip 1.71 kg.cm static (v3.1
  1.74). Spin-in-place hip load +8 % (heavier robot), wheel torque 0.196 kg.cm (11 % of stall, was 9 %).
- Lift poses re-optimised for each robot (`stability_scripts/reopt_v3_2.py`, the research's optimiser):

  | worst joint, kg.cm | v3.1 | v3.2 no ballast | v3.2 with ballast |
  |---|---:|---:|---:|
  | front paw lifted 12 mm (gait), margin 8 | 0.33 | 0.30 | **0.26** |
  | give paw (30 mm up, axle 12 ahead), margin 8 | 0.39 | 0.35 | **0.32** |
  | crossing (four paws, weight over the diagonal) | 0.43 | 0.37 | **0.20** |

  **The firmware keyframes must be re-tuned for v3.2**: the research's v3.1 angles on the v3.2 robot lean too
  far back (give-paw from a puppy sit then peaks at 0.79 kg.cm). The IMU learning rule does this, or use the
  angles in `v3_2_stability_check_output.txt`.

## Clearances
- Leg sweeps (report): knee pods vs belly 2.62-3.54 mm (as v3.1); paw band / pod vs desk over the gait 5.95 /
  6.41 mm (v3.1 4.55 / 5.01); lead corridors unchanged; the rear-leg joint limit is unchanged (hip >= +29 ->
  knee <= +48).
- Paw pods vs the desk in the tilt poses (`stability_scripts/pod_clearance_v3_2.py`, real pod shape, every paw):

  | pose | v3.1 | v3.2 (research angles) | v3.2 re-optimised |
  |---|---:|---:|---:|
  | give paw from stand (8 mm) | 1.6 | 3.1 | **4.7** |
  | give paw from puppy sit (6 mm) | 1.2 | 2.7 | - |
  | curious tilt | 2.2 | 3.7 | - |
  | sniff (back paw up) | 1.4 | 2.9 | - |
  | gait B_FL / crossing | 4.5 / 4.6 | 5.9 / 6.0 | 5.4 / 5.3 |

  The target >= 3 mm is met for the give-paw from the stand (demo this first) and every re-optimised pose;
  the puppy-sit and sniff poses at their old v3.1 angles are 2.7-2.9 mm.
- **Research pose that cannot work:** the "Sit (8 deg)" row (rear knees -48) puts the rear paw pods 6 mm into the
  desk in both v3.1 and v3.2. Keep the firmware sit.

## Open decisions
1. Tuft style Plush (built) or Flick, and its colour (caramel built; a gradient is not printable).
2. The bigger tyre (O-ring stretch 7 -> 19 %). If you would rather not stretch the O-ring that much, set
   `OR_GROOVE_R = 13.9` back in the script: the paws then clear the desk by 1.7-2.5 mm in the give-paw poses.
3. Ballast: buy / cut 2 steel slugs 24 x 7.5 x 15.8 mm (or fill with lead shot). Coins do not fit. Try the tape
   test first (day-1 test 3).
4. Measure the delivered OV5640 flex (needs >= 19 mm from the module edge) and the APDS-9960 chip position
   (assumed centred on the 21 x 15.5 board; the chest window allows +-3 mm).

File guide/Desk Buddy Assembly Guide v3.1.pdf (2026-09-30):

B U I L D M A N U A L

# Desk Buddy

# Assembly Guide

v3.1

October 2026 · first edition

A four-legged desk robot dog with wheels on its paws, a 4.3 inch face and a camera. This guide takes you from printed parts and a box of electronics to a robot that stands up.

Desk Buddy · Assembly Guide v3.1

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
Tool

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
klis

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
al siz

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
uild

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
tion

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
### 6 As

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
t limit

s

6

2
E
Tail | 6

3
F

E

a

r

s | 6

4
G

Clos

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
alib

r

a

tion

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
### 9 Appe

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
e lis

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
colou

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
h on

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
el m

a

p

| 8

2
Wirin

g

t

a

ble

s

| 8

2

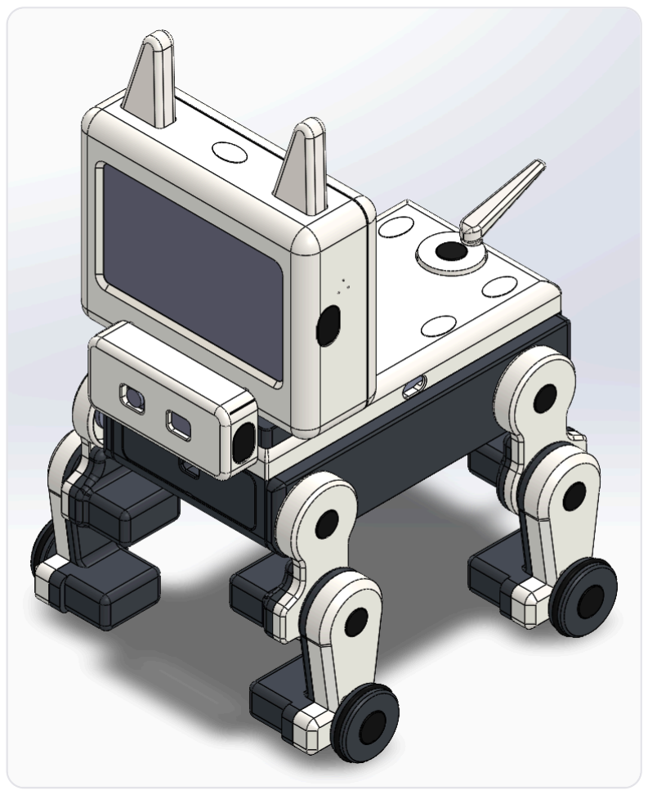
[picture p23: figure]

Desk Buddy · Assembly Guide v3.1 | 3

1
CHAPTER 1

# Before you start

Read this chapter once, all the way through, before you touch a soldering iron. It lists the tools, the safety rules for the battery and the iron, and how every step in this guide is laid out.

## 1.1 What you are building

Desk Buddy is a small robot dog about 17 cm wide. Each
of its four legs has a hip servo and a knee servo, and each paw has a wheel servo, so it can walk slowly or roll. A tail servo wags. Its face is a 4.3 inch touch screen, its eyes are a camera in the muzzle, and it hears you through two microphones.
You will build it in this order: print the parts, check every bought part, build the wiring harness, test everything on the desk, assemble the body, lid, head, legs, tail and ears, and finally switch it on and calibrate it.
Plan on roughly two days of printing at the maker space, an evening for the harness, an evening for the bench test and a weekend for the assembly. Nothing here is hard, but almost everything is small, so work slowly and in good light.

## 1.2 Tools

You already bought most of these. The ones marked get are cheap and worth having before you start: buy them at Jaycar or Bunnings.

Tool | Used for | Status
ES02 soldering kit and digital multimeter | Every soldered joint; measuring voltages and checking for shorts | bought (EU plug: use the plug adapter)
Solder, 0.7 to 0.8 mm, rosin core | Thin solder is easier on small pads | get if the kit has only thick solder
Flux pen | Makes solder flow onto old or oxidised pads | get (Jaycar)
Small Phillips screwdrivers, PH0 and PH1 | All the M2 screws | at home
Flush cutters (PLATO 170) | Trimming wires and cleaning prints | bought
Wire stripper | About 40 wire ends; cutters nick the strands and nicked wires snap later | get
2.0 mm drill bit (used by hand, no drill) | Opening the servo horn holes so M2 screws pass | get
Digital caliper | Measuring the servos before printing | bought
Superglue, cable ties, foam tape, heat-shrink | Mics, foil pads, slack loops, boards, joints | bought

Tool | Used for | Status
Breadboard and jumper wires | The bench test | bought
Masking tape and a fine marker | A name flag on every lead | at home
Laptop with PlatformIO, a USB-C data cable, a 5 V 2 A phone charger | Uploading the test sketch; charging | at home
A mug or small box | Propping the robot up so its wheels are off the desk | at home

## 1.3 Safety

SOLDERING AND FUMES
The iron tip is about 350 degrees C. Always put it back in its stand, never on the bench. Work by an open window or with a small fan pulling the smoke away from your face, not towards it. Wash your hands after soldering and before you eat. Wear glasses when you trim wire ends, because they fly.

18650 CELLS
These cells hold a lot of energy. Never let anything metal touch both ends of a cell: no loose cells in a pocket or a bag with keys or coins. Never use a cell with a torn or dented wrapper. Check the + and - marks twice before a cell goes into the holder, every single time. Never mix the Samsung cells with the spare Tinker cells, and always change both cells together.

USE THE FUSE
The protection board only cuts off at about 20 A, which is enough to melt thin wire inside a plastic shell. The 7.5 A fuse is what protects the robot. Never bridge it, and never replace it with a bigger one.

POWER OFF BEFORE YOU TOUCH THE WIRING Switch the robot off before you plug or unplug anything. For any work inside the tub, also take the cells out. Keep your fingers away from the legs while the robot is switched on: servos are strong enough to pinch.

HEAT
The printed parts are PLA, which softens at about 55 degrees C. Never leave the robot in a car or in direct sun behind a window.

## 1.4 How to read this guide

Every assembly step looks the same. Here is what each part of a step means. A2 The step number and title. The letter is the
section: A Body, B Lid, C Head, D Legs, E Tail, F Ears and G
Close up.
The picture. The part you fit in this step has an orange outline. A bought part it holds, like a servo or a sensor board, has a blue outline. Everything already built is faded. Orange arrows show which way a part moves to go on. You need. The parts and the screws for this step. Screws are colour-coded by length, the same way every time:

The text. Read it all before you pick anything up. Then do it in order.

LEFT, RIGHT, FRONT AND BACK
Left and right always mean the robot's own left and right, as if you were sitting on it facing forward. The front is the end with the head. So when you face the robot, its left side is on your right.

PART NAMES
Printed parts are named by their file, for example Thigh_FrontLeft_Outer . Bought parts use the names in the Parts check chapter.

COLOURS
Printed parts come in three colours: | cream, | brown
and | black (the small caps and covers). Most pictures in
this edition were rendered before the colours were chosen, so they show the parts in off-white and dark grey; the plainer views drawn straight from the print files already use the new colours. Print the off-white parts in cream and the dark grey parts in brown. The small caps and covers stay black.

Check tells you how to know the step went right. Common mistake is the thing people most often get wrong at that step.

SCREWS INTO PLASTIC
All screws are M2 self-tapping: they cut their own thread in the printed hole. Drive each screw in once before the part goes on, then take it out (this is called pre-threading). Tighten until the head touches, then a quarter turn more, and stop. Over-tightening strips the thread.

2
CHAPTER 2

# Printing

The robot is 55 printed parts on nine print jobs, about 386 g of PLA and about $43 at the Deer Park Library maker space. Print the small test plate first, check the fits with the real parts, and only then print the rest.

## 2.1 Measure one servo first

The printed parts are designed around a few servo measurements the sellers do not publish. When the servos arrive, measure one MG90S with the caliper and compare it with the table. If any number is off by more than about 0.2 mm, stop: the numbers go into the CAD script ( cad/build_print_parts_v3_1.py ), the parts are rebuilt, and you print from the new files.

Measure on the servo | Design value | Your value
Underside of the mounting tabs to the top of the rectangular gear case | 4.5 mm
Underside of the tabs to the top of the round boss the spline comes out of (boss diameter 11.8) | 7.5 mm
Case bottom to the tab underside | 21.0 mm
Tab underside to the spline top | 14.4 mm
Tab thickness | 2.8 mm
Distance between the two tab holes | 28.15 mm
Tab ear corners: round (R1.1 or more) or square? If square, file the two corners that face down to 1 x 45 degrees | round
The three servo wires twisted into a round bundle: must pass a 2.6 mm hole | 2.4 mm
Cross horn from the servo bag: centre to tip / arm thickness / arm width / how far its top sits above the spline | 11.5 / 1.8 / 6.6 / 1.0
The tyre O-ring's thickness (the 31 mm OD ring from the assortment) | 2.4 mm

## 2.2 What to ask at the maker space

Book the UltiMaker 2+ Connect (0.4 mm nozzle, PLA) and take the STL files from cad/print_v3_1_stl on a USB stick. You can read this out to the staff:

THE REQUEST
"I'd like to print nine small PLA jobs for a robot, plus one test plate first. The settings are 0.2 mm layers, 2 walls, 0.8 mm top and bottom, 15 percent gyroid infill and no supports. Please use a 5 mm brim on the two long flat plates, G1 and W1, and a skirt on the rest. The colours are cream, brown and black PLA. Every plate is under 60 grams and fits the bed; Cura's Arrange All lays each one out. Could you tell me which filaments you have in those colours, and whether the 60 gram price band applies per job?"

Slicer settings (UltiMaker Cura)

Layer height | 0.2 mm
Line width | 0.4 mm
Wall line count | 2 (0.8 mm)
Top / bottom thickness | 0.8 mm (4 layers)
Infill | 15 %, gyroid
Supports | none (see note A)
Adhesion | brim 5 mm on G1 and W1, skirt on the rest

Why 2 walls: the hidden walls are 1.6 mm, exactly four lines of a 0.4 mm nozzle, so two walls per side print them solid. Three walls

NOTE A - ROUND EDGES ON THE BED
The lid, the head front and the head back print with their visible rounded face on the bed, so the first 1 to 2 mm of that edge grows outward over nothing. PLA usually prints this with a slightly soft first millimetre. If the first lid
shows a drooping edge, reprint that plate with "Support: touching build plate" at 60 degrees, and sand the edge lightly.

would add about 37 g and take the robot over its 400 g print budget.

ORDER OF PRINTING
Print T1 first and test it (2.3). If a fit is wrong, the design is corrected and T1 is reprinted before anything else. Then print B1 (cheap, and the caps are needed early), then the body plates, then the legs.

## 2.3 The test plate, T1

T1 costs about $4 and checks every fit that matters with the real parts, before you spend $43 on the robot. Test each coupon like this, and write down anything that does not fit.
Fit_Test_Coupon. Push an MG90S into the servo slot: it
should slide in with light finger pressure and not rattle.
Clip the power switch into its cut-out. Press a screen screw into the boss. Hold a laser board behind the windows. Stretch a 26 mm O-ring into the groove. Lay a cross horn in the horn pocket.
Coupon_Knee_Thigh and Coupon_Knee_Shin. Screw a real MG90S to the thigh coupon with two M2x6. Fit a horn into the shin coupon, press it onto the spline, and press a 12 mm cap into its seat. Thread a servo lead through the lead chamber and swing the joint back and forth 500 times: the lead must not rub through or jam.
Coupon_Snap_White and Coupon_Snap_Graphite. Click the hook into the catch: it should click in firmly and release with a thumbnail. Press a 12 mm and a 14 mm cap into the two seats: snug, and removable with a fingernail in the notch.

## 2.4 The print jobs

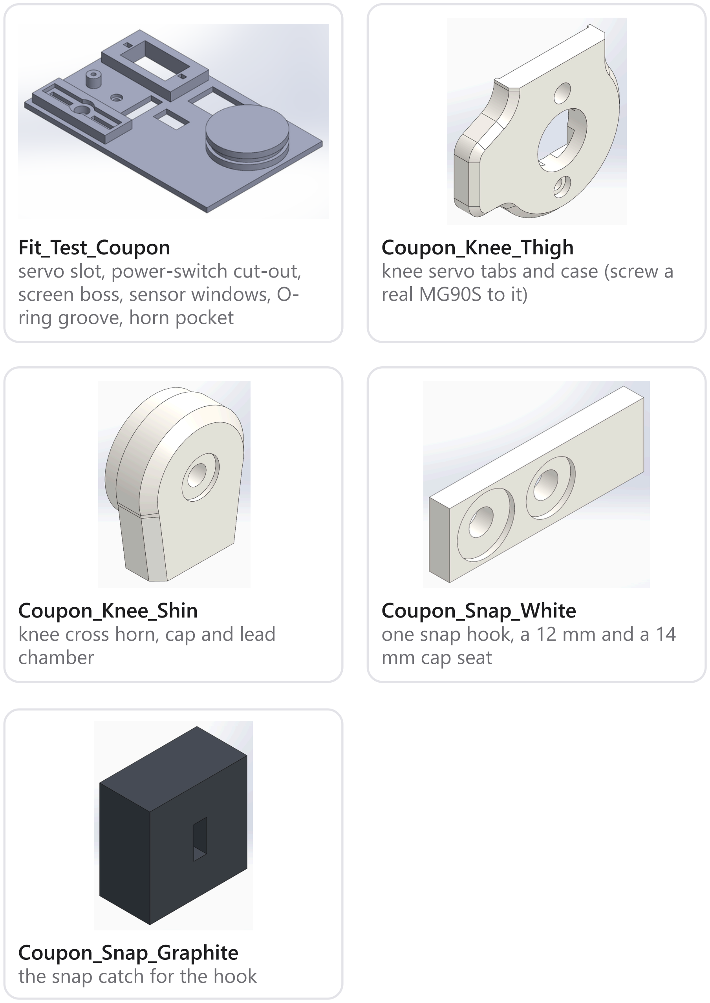
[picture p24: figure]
Fit_Test_Coupon servo slot, power-switch cut-out, screen boss, sensor windows, O- ring groove, horn pocket; Coupon_Knee_Thigh knee servo tabs and case (screw a real MG90S to it); Coupon_Knee_Shin knee cross horn, cap and lead chamber; Coupon_Snap_White one snap hook, a 12 mm and a 14 mm cap seat; Coupon_Snap_Graphite the snap catch for the hook

One filament colour per plate. Both price columns are shown: the maker space's price bands ($1 up to 10 g, $2 up to 20 g, $4 up to 40 g, $6 up to 60 g) and the $1.10 per 10 g rate. Skirts and brims add a gram or two, so G1, W1 and W4 may land just over 60 g.

Order | Plate | Filament | Parts | Grams | Band price | $1.10 / 10 g
1 | T1 | any | Fit_Test_Coupon, both knee coupons, both snap coupons, 1 x 12 mm + 1 x 14 mm cap | 26.5 | $4.00 | $2.92
2 | B1 | black | 13 caps, 4 port doors and blanks, screw plugs, screen washers | 4.6 | $1.00 | $0.51
3 | G1
| | brown | tub + 2 bands | 56.6 | $6.00 | $6.23
4 | W1 | cream | lid + 2 ears + tail root + tail | 53.7 | $6.00 | $5.91
5 | G2
| | brown | 2 side panels + battery door + clamp + collar | 54.6 | $6.00 | $6.01
6 | W2 | cream | head front + muzzle | 47.2 | $6.00 | $5.19

Order | Plate | Filament | Parts | Grams | Band price | $1.10 / 10 g
7 | W3 | cream head back + 1 thigh outer | 38.3 | $4.00 | $4.21
8 | W4 | cream | 4 shin outers + 3 thigh outers | 57.9 | $6.00 | $6.37
9 | G3
| | brown | 4 thigh covers + 3 wheels | 37.5 | $4.00 | $4.12
10 | G4
| | brown | 4 shin covers + 1 wheel | 35.3 | $4.00 | $3.88
| Robot, plates 2-
| 10 | | | 385.7 | $43.00 | $42.43
| With the test plate | | | 412.2 | $47.00 | $45.35

## 2.5 Every printed part

The 26 kinds of printed part, with their colour and what each one holds. Parts marked x4 are one per leg. The front-left and back-right thighs are the same shape turned round, and so are the front-right and back-left. The two left shins match, the two right shins match, and all four wheels match.

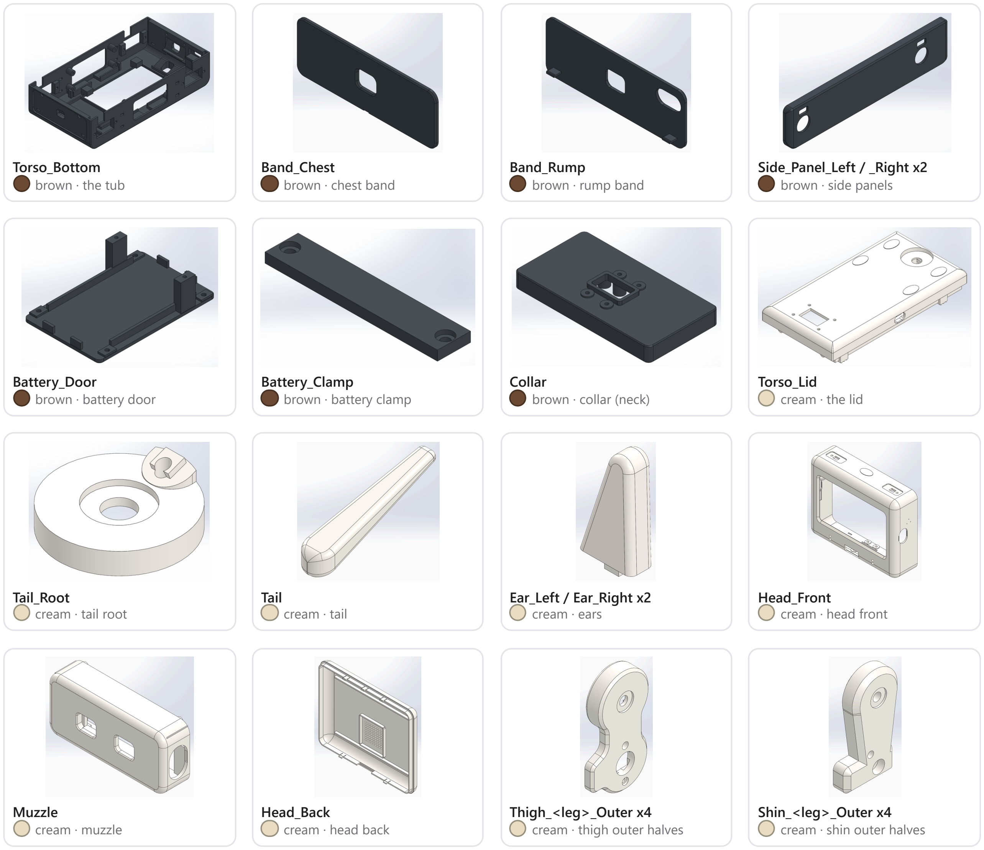
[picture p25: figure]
Torso_Bottom brown · the tub; Band_Chest brown · chest band; Band_Rump brown · rump band; Side_Panel_Left / _Right x2 brown · side panels; Battery_Door brown · battery door; Battery_Clamp brown · battery clamp; Collar brown · collar (neck); Torso_Lid cream · the lid; Tail_Root cream · tail root; Tail; cream · tail; Ear_Left / Ear_Right x2 cream · ears; Head_Front cream · head front; Muzzle cream · muzzle; Head_Back cream · head back; Thigh_<leg>_Outer x4 cream · thigh outer halves; Shin_<leg>_Outer x4 cream · shin outer halves
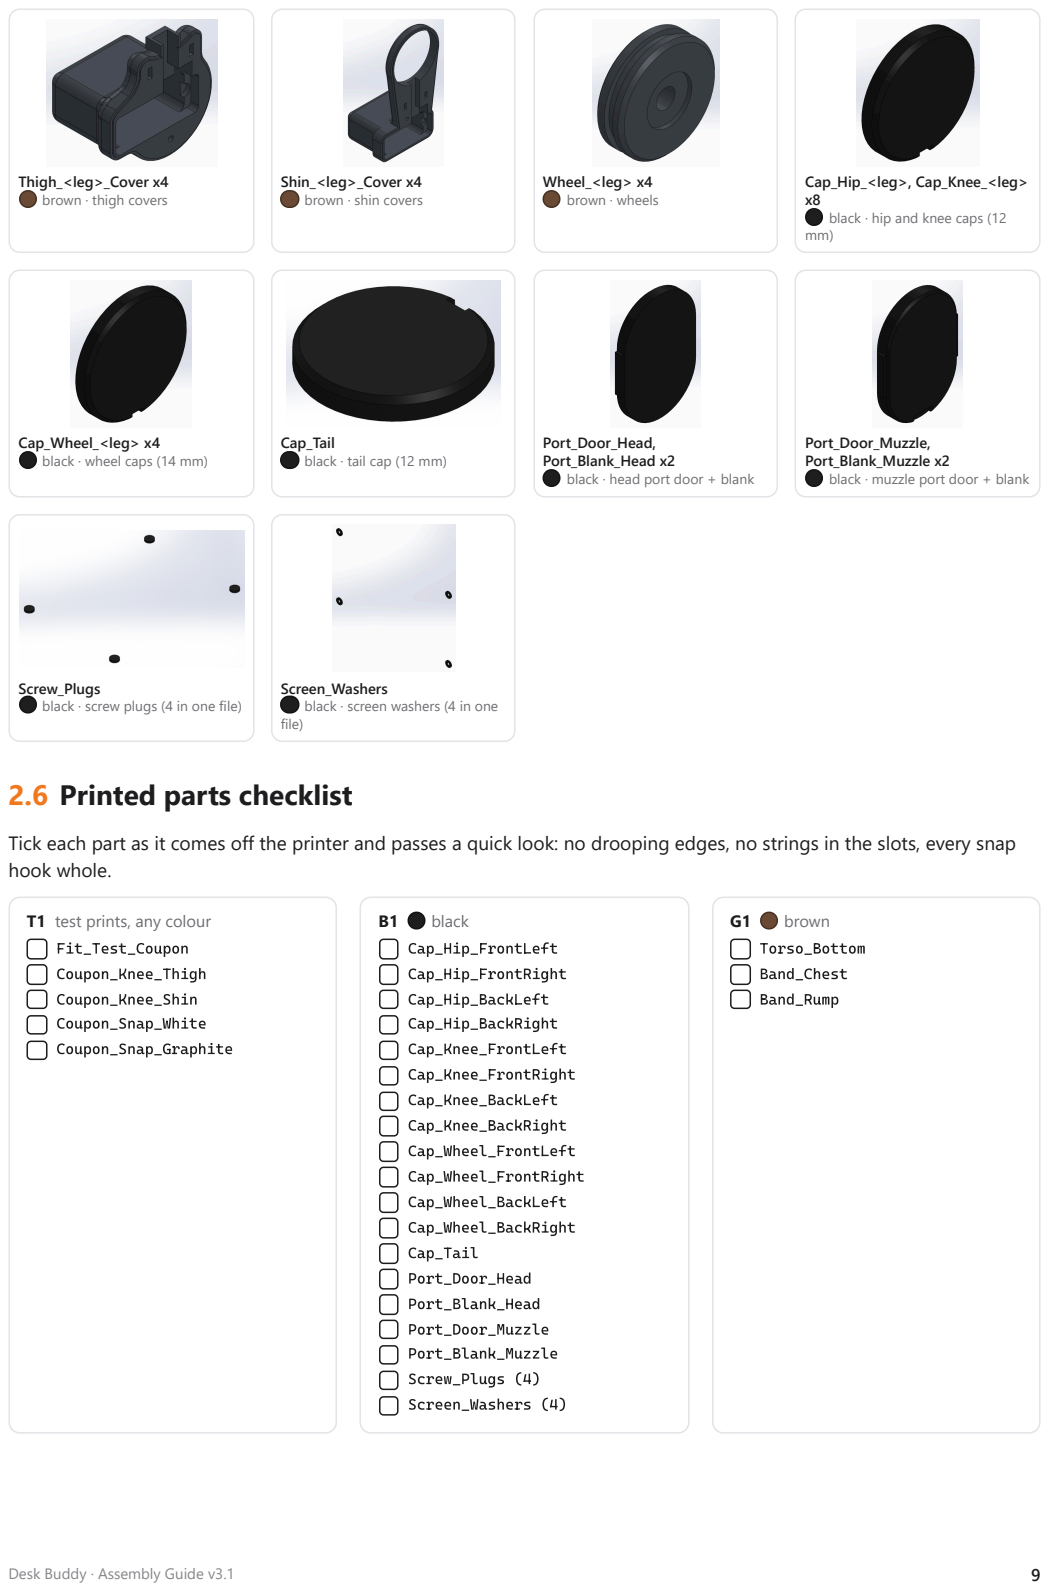
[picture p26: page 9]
Wheel_<leg> x4 brown · wheels; Fit_Test_Coupon; Coupon_Knee_Thigh; Coupon_Knee_Shin; Coupon_Snap_White; Coupon_Snap_Graphite; black; Cap_Hip_FrontLeft; Cap_Hip_FrontRight; Cap_Hip_BackLeft; Cap_Hip_BackRight; Cap_Knee_FrontLeft; Cap_Knee_FrontRight; Cap_Knee_BackLeft; Cap_Knee_BackRight; Cap_Wheel_FrontLeft; Cap_Wheel_FrontRight; Cap_Wheel_BackLeft; Cap_Wheel_BackRight; Cap_Tail; Port_Door_Head; Port_Blank_Head; Port_Door_Muzzle; Port_Blank_Muzzle; Screw_Plugs (4); Screen_Washers (4); brown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

Thigh_<leg>_Cover x4
brown · thigh covers

Shin_<leg>_Cover x4
brown · shin covers

Cap_Hip_<leg>, Cap_Knee_<leg>
black · hip and knee caps (12

Cap_Wheel_<leg> x4
black · wheel caps (14 mm)

Cap_Tail
black · tail cap (12 mm)

Port_Door_Head,
Port_Blank_Head x2
black · head port door + blank

Port_Door_Muzzle,
Port_Blank_Muzzle x2
black · muzzle port door + blank

Screw_Plugs
black · screw plugs (4 in one file)

Screen_Washers
black · screen washers (4 in one
file)

2.6 Printed parts checklist

Tick each part as it comes off the printer and passes a quick look: no drooping edges, no strings in the slots, every snap
hook whole.

T1 test prints, any colour

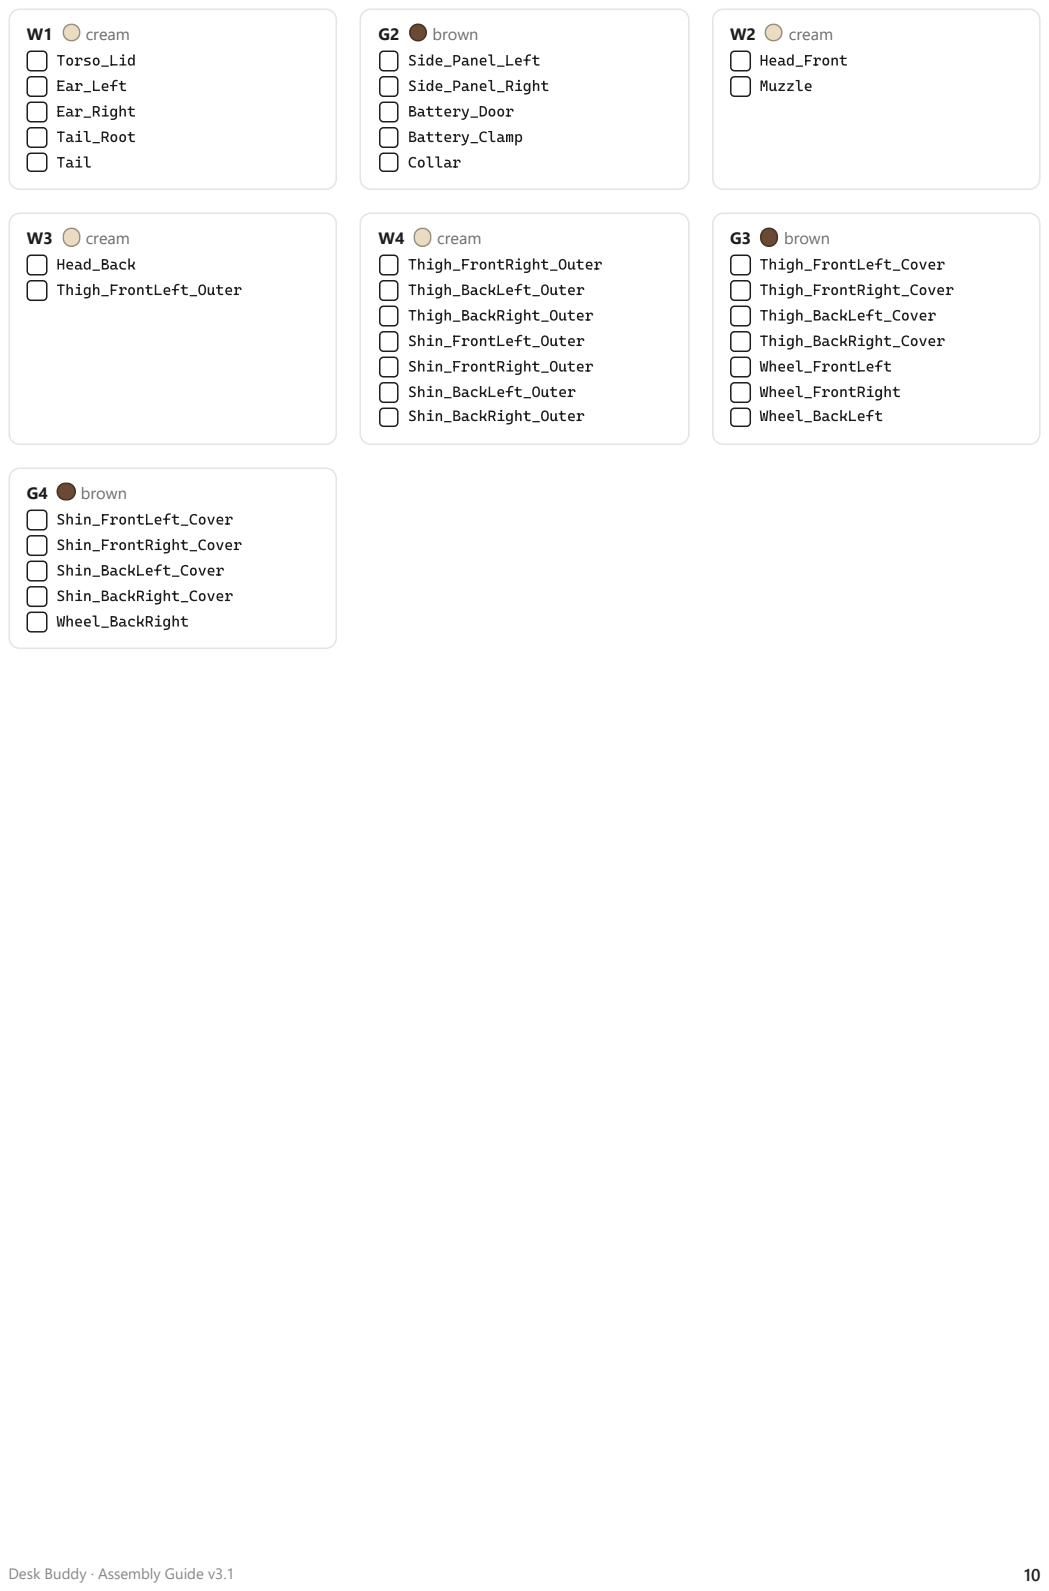
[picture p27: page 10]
cream; Torso_Lid; Ear_Left; Ear_Right; Tail_Root; Tail; brown; Side_Panel_Left; Side_Panel_Right; Battery_Door; Battery_Clamp; Collar; Head_Front; Muzzle; Head_Back; Thigh_FrontLeft_Outer; Thigh_FrontRight_Outer; Thigh_BackLeft_Outer; Thigh_BackRight_Outer; Shin_FrontLeft_Outer; Shin_FrontRight_Outer; Shin_BackLeft_Outer; Shin_BackRight_Outer; Thigh_FrontLeft_Cover; Thigh_FrontRight_Cover; Thigh_BackLeft_Cover; Thigh_BackRight_Cover; Wheel_FrontLeft; Wheel_FrontRight; Wheel_BackLeft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

3
CHAPTER 3

# Parts check

Unpack every bag the day it arrives, tick it off here, and test the electronics that same week (chapter 5). If something is missing or dead, AliExpress disputes are much easier while the order is new.

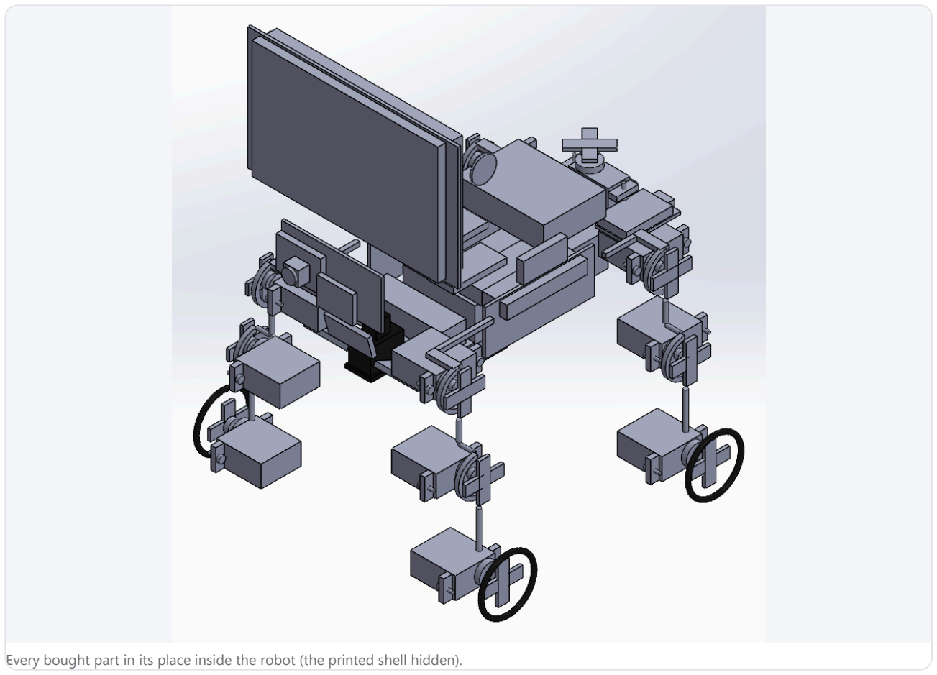
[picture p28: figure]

Every bought part in its place inside the robot (the printed shell hidden).

## 3.1 Bought parts checklist

The quantity is what you should have. "Where it goes" tells you where the part ends up in the robot. The store links are in the Appendix.

Part | Qty | Where it goes | Store and listing
Guition ESP32-S3 4.3" touchscreen board (JC4827W543C) | 1 | Head front, behind the screen window | AliExpress
ESP32-S3 N16R8 camera board + OV5640 camera | 1 | Muzzle (lens in the left window) | AliExpress
ESP32-S3-DevKitC-1 N16R8 | 1 | Not fitted - bench spare | AliExpress
MG90S metal-gear servo, 180 degrees | 10 | 4 hips, 4 knees, tail, 1 spare | AliExpress
MG90S metal-gear servo, 360 degrees (continuous) | 4 | Wheels, one in each paw | AliExpress
PCA9685 16-channel servo board | 2 | Tub, one on each side wall | AliExpress
VL53L0X laser distance sensor | 8 | 7 fitted (chest, rump, 3 desk-edge in the tub floor, 2 sides in the lid) + 1 spare | AliExpress

Part | Qty | Where it goes | Store and listing
MS3625 I2S microphone | 2 | Mic rings on each side of the head front | AliExpress
Cavity speaker 3 W 4 ohm (1.25 mm plug) | 1 | Head back, between its fences | AliExpress
MPU6050 motion sensor (GY-521) | 1 | Under the lid, in its fence | AliExpress
APDS-9960 gesture sensor | 1 | Muzzle, on its shelf behind the right window | AliExpress
MPR121 touch board | 1 | Under the lid, in its fence | AliExpress
Type-C 2S boost charging board | 1 | Tub, raised ledge at the rump; socket in the rump opening | AliExpress
2S 20 A protection board (with balance) | 1 | Tub floor, between its fences | AliExpress
2 x 18650 battery holder (series, wired) | 1 | Battery door | AliExpress
Mini560 buck converter, fixed 5 V 5 A | 2 | On the perfboard hub under the lid | AliExpress
KCD1 rocker switch | 1 | Front of the belly, flush in its recess | AliExpress
Mini blade fuse holder, 7.5 A, 16 AWG | 1 | On top of the protection board | AliExpress
M2 self-tapping screw kit (500) | 1 | Everywhere - see the screw chart | AliExpress
Dupont jumper wires (120) | 1 | Signal wiring | AliExpress
MX1.25 4-pin pre-wired plugs (10) | 1 | Plugs for the screen board ports P1, P3, P4 | AliExpress
Perfboard 5 x 7 cm (5) | 1 | The power and sensor hub under the lid | AliExpress
3M double-sided foam tape, 20 mm | 1 | Sensor boards and the hub | AliExpress
Heat-shrink tubing (127) | 1 | Every soldered joint | AliExpress
830-point breadboard | 1 | Tool: bench test | AliExpress
ES02 soldering kit + digital multimeter | 1 | Tool | AliExpress
PLATO 170 flush cutters | 1 | Tool | AliExpress
Digital caliper 150 mm | 1 | Tool: measure the servos before printing | AliExpress
Samsung 35E 18650 cell, 3500 mAh, button top | 2 | In the battery holder | TinkerTech AU
Tinker 25R 18650 cell, 2500 mAh (spare pair) | 2 | Spare pair - never mix with the Samsungs | TinkerTech AU
Heavy-duty hook-up wire 7.5 A, red (WH3040) | 2 m | Battery and servo power (+) | Jaycar
Heavy-duty hook-up wire 7.5 A, black (WH3041) | 2 m | Battery and servo power (-) | Jaycar
1000 uF 16 V capacitor (RE6220) | 2 | Hub: one across each Mini560 output | Jaycar
2.2 kOhm resistors (RR0580) | 1 | Hub: wheel-stop pull-up on the OE line | Jaycar

NBR O-ring assortment, OD 21-35 mm x 2.4 mm

1 Wheel tyres: use the 31 mm OD rings (about 26.2 mm inside), 4

A flux pen, thin rosin-core solder (0.7 to 0.8 mm), a wire stripper and a 2.0 mm drill bit (see Tools, 1.2).
A USB-C data cable. Test yours: plug your phone into the laptop with it. If the phone shows up as a device, the cable can

The tyres come from the AliExpress NBR O-ring assortment (outside diameter 21 to 35 mm, all 2.4 mm thick). Take out four rings of the 31 mm outside diameter size, plus a spare: each is about 26.2 mm across the inside, which is what the wheel groove is designed for. Check the thickness with the caliper (2.4 mm), and try one on a wheel (or the groove on the Fit_Test_Coupon) before you fit all four.

## 3.2 Check the listings match

These look-alike parts cost less and are easy to get wrong. Check each one against the part in your hand. Screen board: the variant must be "C", which means
capacitive touch (the GT911 chip). The "N" and "R" variants
look the same.
2S charging board: it must be the "boost" type with 5 V input. A look-alike "buck" board (TP5100 type) cannot charge from USB.
Battery holder: the SERIES version, with one red and one black lead and the two cells end to end in series.

Microphones (MS3625): each must have an I2S interface and an L/R pin.
Speaker: the "1.25 terminal" variant, so it plugs straight into the screen board.
Servos: ten 180 degree MG90S and four 360 degree MG90S. The 360 ones keep turning when you push the pulse off centre; flag them "360" the day they arrive, because they look the same.

## 3.3 Screw chart, actual size

If you print this page, turn off "fit to page". Check the ruler below measures exactly 50 mm with the caliper before you trust

All the assembly screws are M2 self-tapping screws from the 500-piece kit. Lay a screw on an outline to find its length (measured under the head), and sort them into three cups before you start. The horn screws come in the servo bags; keep

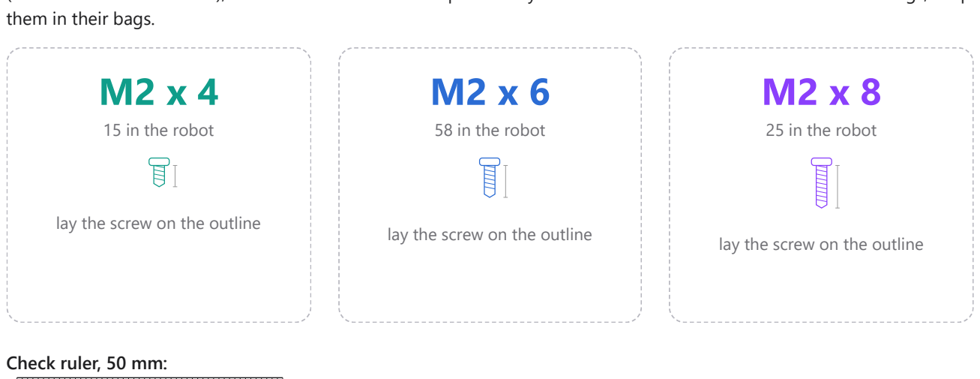
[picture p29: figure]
them in their bags. M2 x 4; 15 in the robot; lay the screw on the outline; 58 in the robot; 25 in the robot; Check ruler, 50 mm:

0 | 10 | 20 | 30 | 40 | 50

Screws per chapter
Count these out into a small cup for each chapter before you start it. If a cup is empty at the end of a chapter and nothing is left over, every screw went in.
Chapter | M2x4 | M2x6 | M2x8 | What for
A Body | - | 12 | 2 hip servos 8 x M2x6, servo boards 4 x M2x6, battery clamp 2 x M2x8
B Lid | 4 | 2 | 4 | tail servo 2 x M2x6, touch pads 4 x M2x4, collar 4 x M2x8
C Head | 1 | 4 | 8 screen 4 x M2x6, head touch pad 1 x M2x4, muzzle 4 x M2x8, head to collar 4 x M2x8
D Legs (all four) | 8 | 32 | 8 | per leg: hip horn 2 x M2x4; knee servo, wheel servo, knee horn and wheel horn 2 x M2x6 each; 2 covers 1 x M2x8 each
E Tail | 2 | - | 1 tail horn 2 x M2x4, tail to root 1 x M2x8
F Ears | - | - | 2 | one M2x8 per ear
G Close up | - | 4 | - lid to tub 4 x M2x6
7 First power- on | - | 4 | - | battery door 4 x M2x6
Total | 15 | 58 | 25 plus 13 horn screws from the servo bags

4
CHAPTER 4

# Wiring

You build the whole wiring harness on the desk first: the battery pack, the power switch and fuse, and the hub with its two 5 V modules. The Bench test in chapter 5 then runs on this real harness, and the Assembly chapter only has to plug it in.

This chapter comes before the bench test because every test needs the battery and the 5 V modules. Read the ten rules first. They come from the parts audit, and each one prevents a way of destroying a board.

## 4.1 The ten wiring rules

RULE 1
Never use the screen board's BAT port. That port is for one 3.7 V cell, and the 7.4 V pack would destroy the board. Feed 5 V into port P1, using only its 5 V and GND wires. Check each wire against the printed labels with the multimeter first.

RULE 2
Sensors get 3.3 V only. Every sensor, and the logic pin (VCC) of each servo board, runs on 3.3 V. Only the green V+ screw terminal of the servo boards gets 5 V. Before you connect any module, measure its SDA and SCL pins: they must read 3.3 V or less.

RULE 3
Build the battery pack in this order. Take the cells out of the holder. Solder a short wire to the metal link between the two cell positions: this is the middle wire the protection board needs. Check that the two cells are within 0.05 V of each other. Connect negative first, then the middle wire, then positive. Plug the charger in once to wake the protection board up.

The fuse comes straight after the protection board. It sits before both the charger and the switch, so a short anywhere in the robot blows the fuse instead of cooking

Charge with the robot switched off. Use a 5 V, 2 A phone charger and a USB-A to USB-C cable. This charger cannot

RULE 6
Unplug the 5 V leads before you plug in the laptop. Before you connect a USB cable to the screen board or the camera board, unplug that board's 5 V lead from the hub. Two power sources on one board can damage it or the laptop port.

RULE 7
Wheel stop. The servo boards' OE pin goes to IO14, with the 2.2 kOhm resistor to 3.3 V. Do not use 10 kOhm, and never use IO46. The firmware turns on the watchdog, which restarts the board if the code freezes; while it restarts, OE is pulled high and every wheel stops. Run the first tests with the robot propped on a block.

Battery limits in the code. The firmware warns at 7.0 V, and at 6.8 V it parks the robot and switches the servos

Speaker. It plugs into the "Speak" port. Never connect

Servo setup. Centre each leg servo before you fit its horn. Each wheel servo's stop point is found in software.

## 4.2 The power path

HUB (under the lid) | BATT-SW 7.4 V, only when switched on

Every GND symbol is the same wire: the thick black ground that starts at the protection board's P- and meets at the hub.

Red = + (thick where the servo current flows) Black = ground White = battery level

Power flows one way. The two cells in series make about 7.4 V. The protection board stops over-charge, over-drain and shorts, and the 7.5 A fuse comes straight after it, before both the charger and the switch. The switch feeds the hub, where two Mini560 modules each make 5 V: module #1 only for the servos, module #2 only for the screen and camera boards. They are kept apart so the servos' current spikes cannot reset the brain. A 1000 uF capacitor across each output smooths the spikes. A 10 k and 4.7 k resistor pair lets the screen board read the battery level on IO5.
The charger connects after the fuse and before the switch, so it charges the cells whether the robot is on or off. Switch the robot off to charge.

## 4.3 Build the battery pack and power leads

Do all of this with the cells out of the holder. They go in for the first time in the bench test (5.3), and come out again before

1. Middle wire. Inside the cell holder, find the metal link that joins the two cell positions. Put a touch of flux on it, and solder on a 10 cm thin wire. Be quick: the holder's plastic melts. This wire goes to the protection board's BM (middle) pad.
2. Holder to protection board. Shorten the holder's red and black leads to about 12 cm: long enough for the battery door to come off and sit beside the robot while it is still wired. Solder black to B-, the middle wire to BM, and red to B+.
3. Fuse. Solder one lead of the fuse holder to P+. Cut two thick red wires: 8 cm for the charger and 12 cm for the switch. Twist both onto the fuse holder's other lead, solder the joint, and cover it with heat-shrink.
4. Charger. Solder the 8 cm red wire to the charger's BAT+ (sometimes marked OUT+). Solder an 8 cm thick black wire from P- to the charger's BAT-.
5. Switch. Solder the 12 cm red wire to one switch terminal and a 25 cm thick red wire to the other; that one goes to the hub's BATT-SW pad. Solder a 25 cm thick black wire to P- as well; it goes to the hub's GND.

6. Finish. Slide heat-shrink over every joint before you solder it, then shrink it. Flag every loose end with tape: CHG+,

With the multimeter on beeper mode, P+ to P- must NOT beep, and CHG+ to CHG- must NOT beep. The two switch wires

## 4.4 The signals

One I2C bus from the screen board to every sensor and both servo boards, wired as a star at the hub.

### 2.2 kOhm to 3.3 V pulls OE high when the brain is not running: every servo stops

IO6 = SCK, IO7 = WS, IO15 = SD, shared by both L/R pin: left mic to GND, right mic to 3.3 V

Servo board A outputs
ch 0, 1, 2 front-left hip, knee, wheel ch 4, 5, 6 back-left hip, knee, wheel ch 8 tail

Servo board B outputs
ch 0, 1, 2 front-right hip, knee, wheel ch 4, 5, 6 back-right hip, knee, wheel ch 9 to 15 laser XSHUT (purple wires)

Every sensor, and the VCC pin of each servo board: 3.3 V.
Only the servo boards' green V+ screw terminal gets 5 V.

The screen board is the brain. One I2C bus, on its port P4 (IO17 for data, IO18 for clock, plus 3.3 V and GND), goes down through the collar to the hub, and from there a short lead of four wires goes to every sensor and both servo boards. Each device has its own address, shown in the diagram. The seven lasers all start at the same address, 0x29; at start-up the firmware wakes them one at a time with their XSHUT wires (from servo board B) and gives each a new address.
IO14 is the wheel stop. It drives the OE pin of both servo boards, and a 2.2 kOhm resistor pulls it up to 3.3 V. While the brain runs, it holds IO14 low and the servos work. If the brain crashes or restarts, the resistor pulls OE high and every servo output stops, so the wheels stop.
The two microphones share three wires from port P3. The speaker plugs into the "Speak" port. The camera board only needs 5 V and GND: it talks to the laptop over Wi-Fi.

## 4.5 Build the hub

10 k + 4.7 k divider -> VBAT pad | 2.2 k from the OE pad to the 3V3 rail

one row of 4 header pins per device (13 rows) the lead from the screen board's P4 lands on one row

1. Board. Cut a perfboard to 50 x 35 mm: score both sides along a row of holes with a knife and snap it over the edge of the table.
2. Modules. Place the two Mini560 modules side by side, pads up. Solder the thick BATT-SW red wire to module #1's IN+ and run a short thick red link on to module #2's IN+. Do the same with the thick GND black wire to both IN- pads. The perfboard only holds the modules; the current runs in the thick wires.
3. Capacitors. Lay each 1000 uF capacitor on its side, and solder it across one module's OUT+ and OUT-. The stripe on the capacitor marks its minus leg; it goes to OUT-.
4. Servo power. From module #1's output, solder a 20 cm thick red and black pair for each servo board's green terminal. From module #2's output, make a red and black lead for the screen board (on an MX1.25 plug: use only its 5 V and GND wires, and cut and insulate the other two) and a Dupont red and black pair for the camera board.
5. Resistors. Solder the 10 k from BATT-SW to a spare pad (VBAT), and the 4.7 k from VBAT to GND; add the white wire from VBAT, for IO5. Solder the 2.2 k from another pad (OE) to the 3V3 rail, and the green wires from OE: one to IO14, one to each servo board.
6. Sensor rails. Run four bare wires along the rest of the board as rails: 3V3, GND, SDA and SCL. Solder a row of four header pins across the rails for each device (use the loose header strips that came with the sensor boards). The input from the screen board's P4 lead lands on one of these rows.

Beeper mode: BATT-SW to GND must not beep. Each module's OUT+ to OUT- must not beep. The 3V3 rail to GND must not

## 4.6 Servo boards: address and leads

Board B's address. Each servo board has six small solder pads marked A0 to A5. On the board that will go on the robot's right wall, bridge the A0 pad with a blob of solder across its two halves. That board is now "board B", address 0x41. Leave board A (left wall) as it came, address 0x40. Mark both boards with tape.
Leads. On the six-pin header at the side of each board, connect GND (black), OE (green), SCL (yellow), SDA (blue) and VCC (orange, 3.3 V). Leave the header's V+ pin empty: servo power goes only on the green screw terminal, V+ and GND.

VCC is the chip's own supply, 3.3 V from the hub rail. Putting 5 V on VCC makes the board's data pins 5 V and can damage

## 4.7 Wire colours and lengths

Use one colour for one job everywhere. When a colour is missing from the jumper kit, use any colour and flag both ends with tape. Lengths are estimated from the 3D model, with slack for the lid to stand beside the tub while you work. Cut long, then trim; never cut a servo lead.

red, thick (7.5 A) - battery + after the fuse, switched battery, 5 V to the servo boards
black, thick (7.5 A) - battery - and power ground | red (Dupont) - 5 V to the screen board and camera board
black (Dupont) - every signal ground | orange - 3.3 V to the sensors and the servo boards' logic
blue - I2C data (SDA) | yellow - I2C clock (SCL) | green - wheel stop (servo boards' OE)
white - battery level (to IO5) | purple - laser on/off (XSHUT) | grey - touch pads
brown - microphone lines (mark each one with tape)

## 4.8 Every connection

Tick each row when it is soldered, and again when it is plugged in during Close up (step G1). Power

| From | To | Wire | Length | Note
P1 | Cell holder, black lead (-) | Protection board B- | holder's own lead | as supplied | long enough for the door to sit beside the robot
P2 | Metal link between the two cells | Protection board BM (middle) | thin red or white, soldered | 10 cm | the "middle wire" - solder it with the cells OUT
P3 | Cell holder, red lead (+) | Protection board B+ | holder's own lead | as supplied | connect last (negative, middle, positive)
P4 | Protection board P+ | Fuse holder, lead 1 | red, thick | 5 cm | 7.5 A blade fuse fitted
P5 | Fuse holder, lead 2 | USB-C charger BAT+ (OUT+) | red, thick | 8 cm | the fuse protects the charger too
P6 | Fuse holder, lead 2 (same joint as P5) | Power switch (KCD1) terminal 1 | red, thick | 12 cm
P7 | Protection board P- | USB-C charger BAT- (OUT-) | black, thick | 8 cm
P8 | Protection board P- | Hub GND pad | black, thick | 25 cm | slack so the lid lifts off
P9 | Power switch (KCD1) terminal 2 | Hub BATT-SW pad | red, thick | 25 cm | slack so the lid lifts off
P10 | Hub BATT-SW / GND | Mini560 #1 (servos) IN+ / IN-, Mini560 #2 (boards) IN+ / IN- | red / black, thick | on the hub | 7.4 V in
P11 Mini560 #1 OUT+ / OUT- | PCA9685 A and B, green V+ / GND screw
| | terminal | red / black, thick | 20 cm each | 5 V servo power only
P12 | 1000 uF capacitor #1 | Across Mini560 #1 OUT (+ leg to OUT+) | capacitor legs | on the hub | the stripe marks the - leg
P13 Mini560 #2 OUT+ / OUT- | Screen board port P1: 5 V / GND only | red / black (MX1.25
| | | plug) | 30 cm | through the collar; P1 only, never BAT
P14 | Mini560 #2 OUT+ / OUT- | Camera board 5V / GND pins | red / black (Dupont) | 30 cm | through the collar
P15 1000 uF capacitor #2 | Across Mini560 #2 OUT (+ leg to OUT+) | capacitor legs | on the
| | | | hub

Signals

| From | To | Wire | Length | Note
S1 | Screen board port P4: 3.3 V, GND, IO17, IO18 | Hub 3V3, GND, SDA, SCL rails | orange, black, blue, yellow (MX1.25 plug) | 30 cm | through the collar; IO17 = SDA, IO18 = SCL (the servo sketch checks)
S2 | Hub 3V3 / GND / SDA / SCL | PCA9685 A and B: VCC, GND, SDA, SCL | orange, black, blue, yellow | 20 cm each | VCC is 3.3 V logic - NOT 5 V
S3 | Hub 3V3 / GND / SDA / SCL | MPU6050 (VCC, GND, SDA, SCL) | orange, black, blue, yellow | 10 cm | under the lid
S4 | Hub 3V3 / GND / SDA / SCL | MPR121 (3.3V, GND, SDA, SCL) | orange, black, blue, yellow | 10 cm | under the lid
S5 | Hub 3V3 / GND / SDA / SCL | 7 laser sensors (VIN, GND, SDA, SCL) | orange, black, blue, yellow

10-25 cm 2 in the lid, 5 in the tub

S6 | Hub 3V3 / GND / SDA / SCL | APDS-9960 gesture sensor (VCC, GND, SDA, SCL) | orange, black, blue, yellow | 30 cm | through the collar to the muzzle
S7 | Screen board IO14 | Hub OE pad -> PCA9685 A OE and B OE | green | 30 cm | 2.2 kOhm from the OE pad to 3V3 (wheel stop)
S8 | Hub BATT-SW -> 10 kOhm -> VBAT pad -> 4.7 kOhm -> GND | Screen board IO5 from the VBAT pad | white | 30 cm | reads the battery; after the switch, so it never drains the pack when off
S9 | PCA9685 B channels 9-15 (PWM pin) | XSHUT pin of each laser (see the laser table)
purple | 10-25 cm turns the lasers on one at a time
| | | | | at boot
S10 | MPR121 E0, E1, E2, E3, E4 | Foil pads: back-left, back-right, rump-left, rump-right, head | grey | 5-30 cm | the wire is clamped under the pad screw

S11 Screen board port P3: IO6, IO7,

| IO15 | Both mics: SCK (IO6), WS (IO7), SD (IO15); 3.3 V and GND | brown (MX1.25 plug) | 10 cm | both mics share all three lines
S12 | Left mic L/R pin | GND (right mic L/R pin to 3.3 V) | black / orange | 3 cm | tells the two mics apart
S13 Speaker (1.25 mm plug) | Screen board "Speak" port | speaker's own lead | as
| | | | supplied | never connect a speaker wire to ground
S14 | 13 servo leads | PCA9685 headers (see the servo table); brown wire on the GND row | servo's own lead | do not cut | wheel lead needs about 200 mm, knee lead about 135 mm

## 4.9 Servo and laser channels

Each servo plugs into the servo board on its own side of the robot, so no lead has to cross the tub. Board A is on the left wall and board B on the right wall. The laser on/off (XSHUT) wires all go to board B. The same map is written into the servo test sketch, and the robot firmware must use it too. Every pin and channel is also listed in one table in the Appendix (9.4).

Servo | Servo board | Channel | Lead route
Hip, front-left | A (left wall, 0x40) | 0 straight through the left tub wall
Knee, front-left | A | 1 | front-left leg, through the side-panel slot
Wheel, front-left (360) | A | 2 front-left leg, through the side-panel slot
Hip, back-left | A | 4 | straight through the left tub wall
Knee, back-left | A | 5 back-left leg, through the side-panel slot
Wheel, back-left (360) | A | 6 | back-left leg, through the side-panel slot
Tail | A | 8 down from the lid
Hip, front-right | B (right wall, 0x41) | 0 | straight through the right tub wall
Knee, front-right | B | 1 front-right leg, through the side-panel slot

Servo | Servo board | Channel | Lead route
Wheel, front-right (360) | B | 2 | front-right leg, through the side-panel slot
Hip, back-right | B | 4 straight through the right tub wall
Knee, back-right | B | 5 | back-right leg, through the side-panel slot
Wheel, back-right (360) | B | 6 back-right leg, through the side-panel slot
Laser | Where | XSHUT to board B channel
Front obstacle | behind the chest band window | 9
Rear obstacle | behind the rump band window | 10
Desk edge, front-left | tub floor incline, left of the switch | 11
Desk edge, front-right | tub floor incline, right of the switch | 12
Desk edge, rear | tub floor incline at the rump, centred | 13
Side, left | shelf under the lid, left wall | 14
Side, right | shelf under the lid, right wall | 15

5
CHAPTER 5

# Bench test

Test every servo, board and sensor on the desk before any of it goes inside the robot. A dead sensor found now costs five minutes. The same sensor found after assembly means taking the lid, the side panels and a leg off again.

## 5.1 Get ready

Header pins. Solder the header pins onto every sensor board: the eight laser boards, the motion sensor, the touch board, the gesture sensor and the two microphones. Push the pins into the breadboard to hold them straight, lay the sensor on top, and solder. This is good practice before the harder joints.
Software. The servo test sketch is in guide/tools/servo_center . PlatformIO is already installed in the laptop project's Python environment. Every command below is typed in a terminal (PowerShell) in that folder:
& $pio run | # build (checked: builds cleanly, 28 Sep 2026)
& $pio run -t upload | # upload to the screen board
& $pio device monitor | # open the Serial Monitor (Ctrl+C to leave)

One power source per board: while a board is on the laptop's USB cable, unplug its 5 V lead from the hub (for the screen board, the P1 plug).

## 5.2 Screen board on its own

Plug the screen board into the laptop with the USB-C cable, and nothing else. It should light up and run the seller's demo. Touch the screen: the demo should react. That proves the screen, the touch chip and the board.
Before anything overwrites it, back up the factory firmware, so you can always put the demo back:

& $pio pkg exec -p tool-esptoolpy -- esptool.py --chip esp32s3 read_flash 0 0x400000 guition_factory_backup.bin

Keep guition_factory_backup.bin somewhere safe. Do the same for the camera board, and test the camera with the seller's example sketch, using the seller's pin map, not the AI-Thinker one.

## 5.3 Power check with the multimeter

Connect the battery pack and switch you built in 4.3 to the hub, with nothing plugged into the hub's outputs. Put the cells in the right way round (black lead to middle wire first), wake the protection board by plugging the USB-C charger in for a few seconds, and switch on.

Measure (DC volts) | Should read | Reading
BATT-SW to GND on the hub | 6.0 to 8.4 V
Mini560 #1 (servos) OUT+ to OUT- | 4.9 to 5.2 V
Mini560 #2 (boards) OUT+ to OUT- | 4.9 to 5.2 V
The red and black wires at the screen board's P1 plug, red probe on red | 4.9 to 5.2 V, not minus
VBAT pad to GND | about 0.32 x the battery voltage (1.9 to 2.7 V)

Only when every reading is right, switch off and plug in the servo boards' green terminals, the P1 plug and the camera board. Switch on and measure the two module outputs again: they must still read 4.9 to 5.2 V.

## 5.4 Centre every servo

A servo's horn must go on while the servo sits at its centre, 90 degrees, or the leg will stand crooked. The test sketch does this for all thirteen servos at once, and keeps them there.
1. Unplug P1. Connect the laptop to the screen board and upload the sketch ( & $pio run -t upload ). Open the Serial Monitor.
2. Plug the servos into the servo boards by the channel table (4.9), brown wire on the GND row. For the bench test they can lie loose on the desk, with no horns fitted.
3. Switch the battery on. Every 180 degree servo moves to its centre and holds; the 360 degree wheel servos stop or creep slowly.
4. Type n and press Enter. The first servo in the table is selected and wiggles, so you know which one it is. Put its name flag on its lead. Repeat n for all thirteen. Type t to sweep the selected servo from 60 to 120 degrees and back: it should move smoothly without grinding.
5. Switch off. From now on, do not turn a servo's shaft by hand, or it is no longer centred. If you do, run the sketch again. At start-up the sketch tries SDA on IO17 first and swaps to IO18 if no servo board answers, lists every device on the bus by name, and says "found" or "NOT FOUND" for each servo board. Type h for the list of commands.

## 5.5 Test the sensors

Plug each sensor into a row of the hub, one at a time at first. After each one, type s in the Serial Monitor and check it appears in the list.

Device | Address in the scan | Extra test
Servo board A / B | 0x40 / 0x41 (0x70 may also show at start-up: ignore it) | Servos centre at start-up

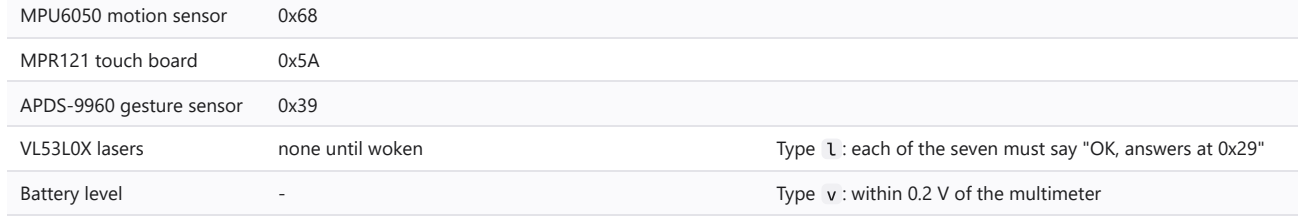
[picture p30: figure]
MPU6050 motion sensor; MPR121 touch board; APDS-9960 gesture sensor

VL53L0X lasers | none until woken | Type l : each of the seven must say "OK, answers at 0x29"
Battery level | - | Type v : within 0.2 V of the multimeter

Cheap copies of these sensors sometimes report a different chip ID. If a sensor does not appear at all, check its wires first; if it appears at an unexpected address, write the address down rather than calling the part dead. Test the spare laser too, and keep it for later.

## 5.6 Wheel stop points and a servo strength test

Wheel stop points. Select each wheel servo with n , then press + or - until it stops completely. Write the number into the calibration table in chapter 7.
Strength test (spare servo). The knees work hard. Hang about 450 g (a full water bottle) from the spare 180 degree servo's horn, 25 mm from the shaft, with the servo held at centre by the sketch, for 5 minutes. Feel for heat and listen for buzzing. Warm is fine. Too hot to hold, or a constant loud buzz, means the knees need stronger servos: tell the lead before assembly.
Afterwards, switch off and take the cells out again. They stay out until chapter 7.

All thirteen servos centre and sweep, both servo boards and every sensor show in the scan, all seven lasers answer, the battery reading matches the multimeter, and the camera board streams a picture.

6
CHAPTER 6

# Assembly

Seven short sections, in this order: the body (tub), the lid, the head, the four legs, the tail, the ears, and closing it all up. The body, lid and head are built as separate pieces; the legs go on the body, and the lid with the head closes it at the end.

Before you start each section, count its screws into a cup
(3.3), lay out its parts, and read all its steps once.
Every servo must be centred before its horn goes on (5.4). If you turned a shaft by hand since then, run the servo sketch again first.
Keep the cells out of the robot for the whole of this chapter. They go in during chapter 7.
Section | Steps | Screws
A Body (tub) | A1-A9 | 12 x M2x6, 2 x M2x8
B Lid | B1-B7 | 4 x M2x4, 2 x M2x6, 4 x M2x8
C Head | C1-C7 | 1 x M2x4, 4 x M2x6, 8 x M2x8
D Legs, x4 | D1-D11 | 8 x M2x4, 32 x M2x6, 8 x M2x8, 12 horn
E Tail | E1 | 2 x M2x4, 1 x M2x8, 1 horn

The finished robot with its shells drawn see-through: every board, servo and sensor in its place.

SECTION A

# A Body

The tub holds the four hip servos, the two servo boards, the protection board and fuse, the charger, the power switch and five of the seven lasers. The battery door carries the cell holder. The side panels close the sides.

## A1 Get to know the tub

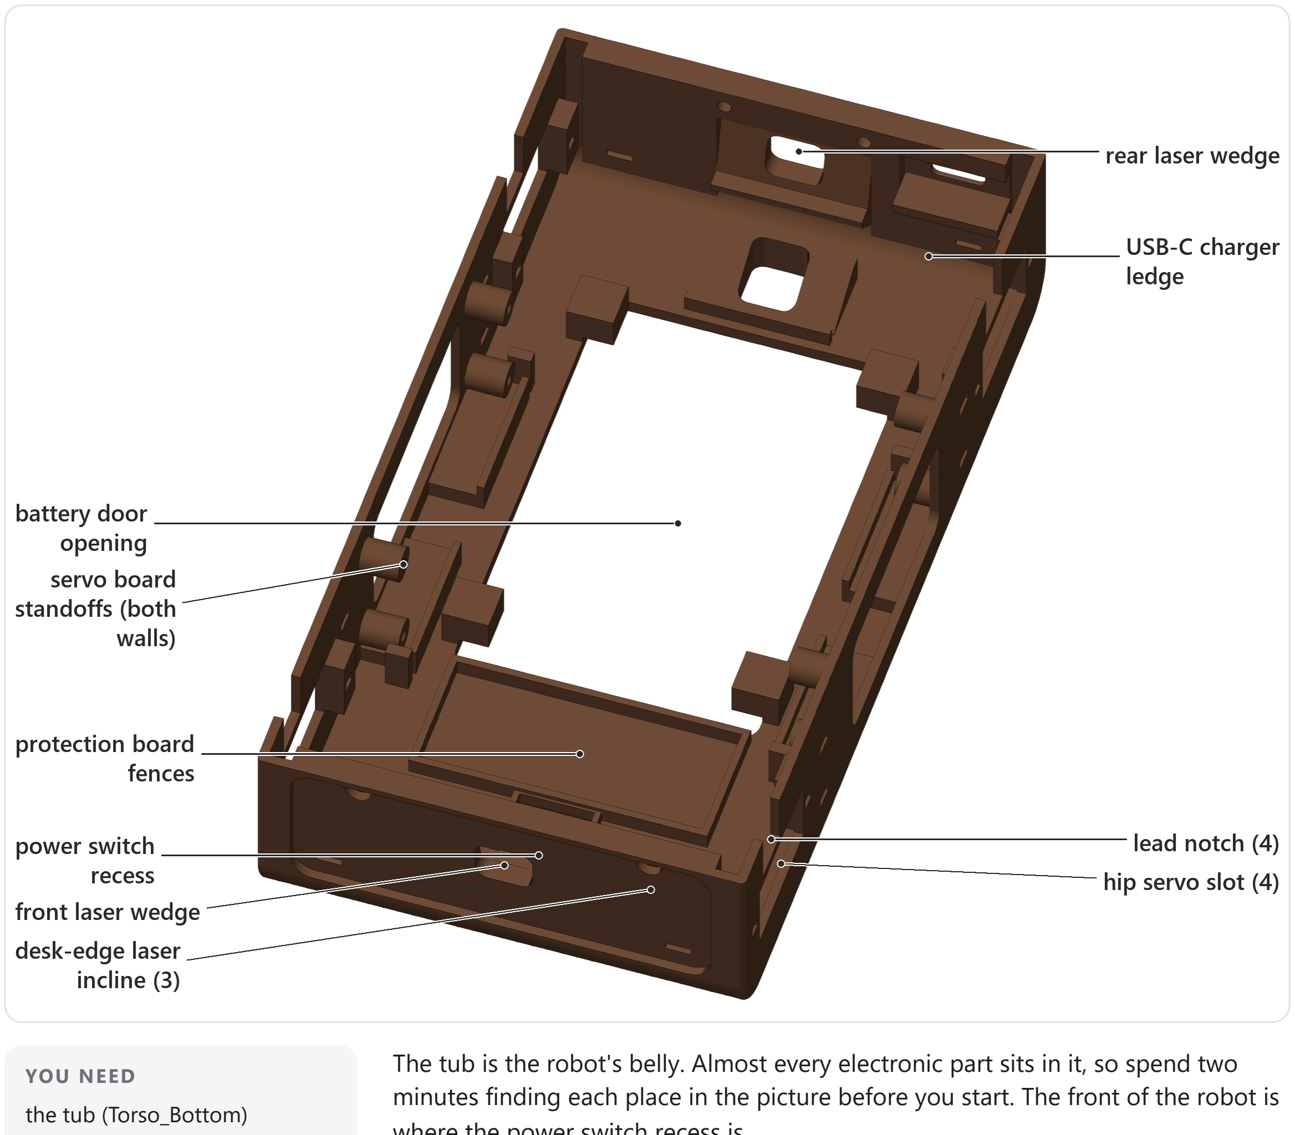
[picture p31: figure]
YOU NEED the tub (Torso_Bottom)

The tub is the robot's belly. Almost every electronic part sits in it, so spend two minutes finding each place in the picture before you start. The front of the robot is where the power switch recess is.
Clean the print first: pull off any brim, snip stray strings with the flush cutters, and make sure every slot and window is open.
Pre-thread the screw holes you will use in this chapter. Drive an M2x6 screw into each one and take it out again. The first time is the stiff one, and doing it now, with nothing fitted, means you never have to lean on a finished part.

CHECK
All four hip slots are clean, and a servo slides into each one from outside without forcing.

COMMON MISTAKE
Driving a screw into an un-threaded hole on a thin wall. Go slowly, straight, and stop as soon as the head touches.

## A2 Hip servos into the tub

4 x MG90S 180 degree servo, centred (Bench test, step 5.4)

### 8 x M2 x 6

Mark each servo lead with a tape flag before you fit it: HFL, HBL, HFR and HBR, for hip front-left, back-left, front-right and back-right. Left and right are always the

Push each hip servo through its slot in the tub wall from the outside, plug and lead first. The two mounting tabs stay outside, flat against the wall, and the round output boss points outward.
Fix each servo with 2 x M2x6 through its tabs. The screws that came in the servo bag also fit.

CHECK
Each servo's tabs sit flat on the wall with no gap, and its output shaft sits in the middle of the round boss hole when you hold a side panel against it.

COMMON MISTAKE
Trying to fit the servo from inside the tub. The tabs must be outside, so the lead goes in first.

## A3 Servo boards on the side walls

2 x PCA9685 servo board (A0 pad bridged on board B)

### 4 x M2 x 6

Each servo board stands upright against a side wall, on four printed standoffs. The servo header rows run along the top edge and the green V+ screw terminal sits in the gap at the bottom middle.
Board A goes on the robot's left wall. Board B, the one with its A0 pad bridged with solder (Wiring, step 4.6), goes on the right wall.
Screw each board through its two upper holes into the upper standoffs, 2 x M2x6 per board. The two lower standoffs are spacers only: a screwdriver cannot reach them square, so leave them empty.

The boards do not rock, and the servo headers face the middle of the tub.

Swapping the boards. If the right board is not the bridged one, both boards answer

## A4 Protection board and fuse

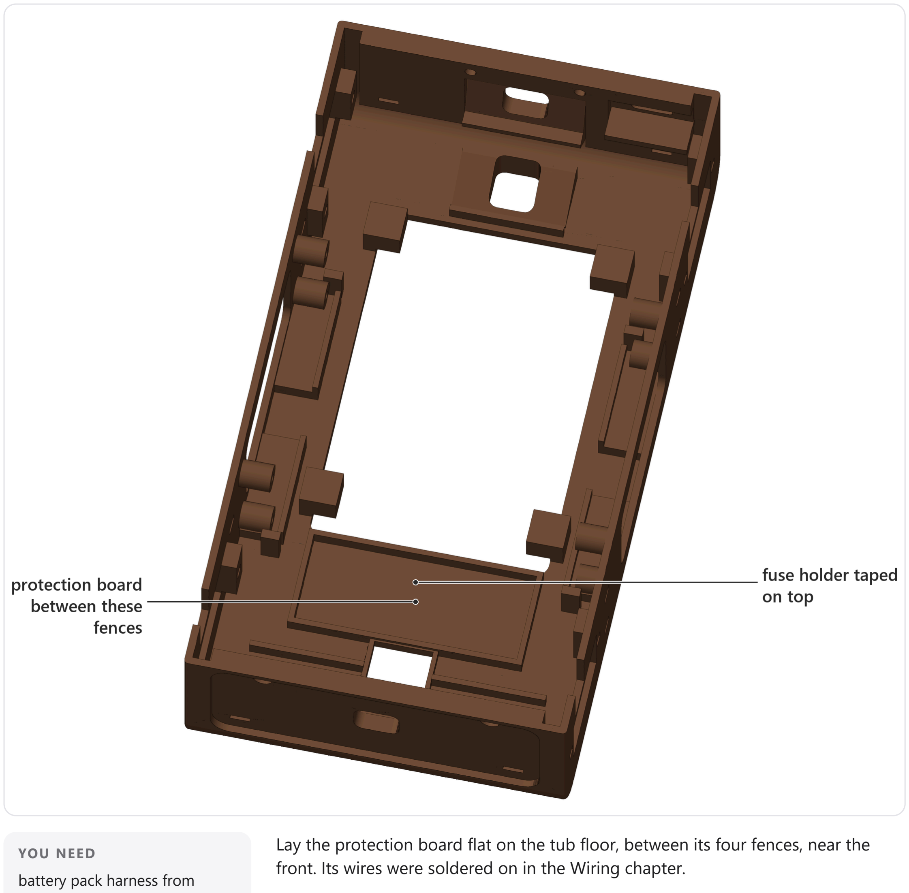
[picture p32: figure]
YOU NEED battery pack harness from

Wiring step 4.3 (protection board, fuse holder, switch leads) foam tape

Lay the protection board flat on the tub floor, between its four fences, near the front. Its wires were soldered on in the Wiring chapter.
Put a strip of foam tape on top of the protection board and stick the fuse holder to it. The 7.5 A fuse stays in.
Lead the three battery wires (black, middle and red) back towards the battery door opening, and the red and black power wires towards the rump, where the charger

The board sits flat and nothing metal on it touches a screw tip or another board.

Leaving the cells in the holder while you work. Keep them out until the First power-on

## A5 USB-C charger at the rump

(already wired, Wiring step 4.3) foam tape

The charger sits on a raised ledge inside the rump wall, above the rear-left hip servo, with its USB-C socket in the opening of the rump wall.
Put a small piece of foam tape on the ledge, slide the board in socket first until the socket face is just behind the opening, and press it down.

CHECK
Plug a USB-C cable in from outside: it goes all the way in without pushing the board back.

COMMON MISTAKE
Taping the board too far back, so the plug cannot reach the socket once the rump band is on.

## A6 Power switch in the belly

wired, Wiring step 4.3)

Turn the tub upside down. The power switch clips into the rectangular cut-out at the front of the belly, from outside, turned so the rocker runs front to back.
Feed its two wires in first, then press the switch in until both side clips snap behind the wall. The rocker sits flush in its recess.
Decide now which way is ON and mark it with a tiny dot of paint or a sticker. The switch is the only way to turn the robot off quickly.

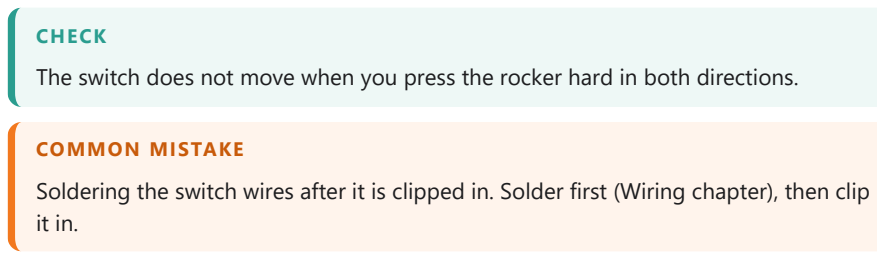
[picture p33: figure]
CHECK; COMMON MISTAKE

The switch does not move when you press the rocker hard in both directions.

Soldering the switch wires after it is clipped in. Solder first (Wiring chapter), then clip

## A7 Five laser sensors in the tub

5 x VL53L0X laser sensor, tested (Bench test)
foam tape

Five of the seven laser sensors live in the tub. Two look forward and backward for obstacles, through the chest and rump windows. Three look down at the desk to stop the robot before an edge: two at the front, either side of the power switch, and one at the rear.
Peel the protective film off each sensor chip. Stick each board to its incline or wedge with a small square of foam tape, chip facing the window, and centre the chip on the hole.
Flag each sensor lead with its name. Their XSHUT wires go to servo board B, channels 9 to 13 (Wiring, laser table).

CHECK
Look through each window from outside: you can see the small black chip in the middle of the hole.

COMMON MISTAKE
Leaving the clear film on the chip. The sensor then reads a short, wrong distance all the time.

## A8 Battery holder onto the battery door

2 x 18650 holder (wired, cells OUT)
battery door and clamp

### 2 x M2 x 8

Lay the empty cell holder between the fences on the inside of the battery door. Its

Put the clamp bar across the holder and screw it to the two posts, 1 x M2x8 each. Tighten until the holder cannot slide, no further.
Do not fit the door to the tub yet. The cells go in, and the door goes on, in the First

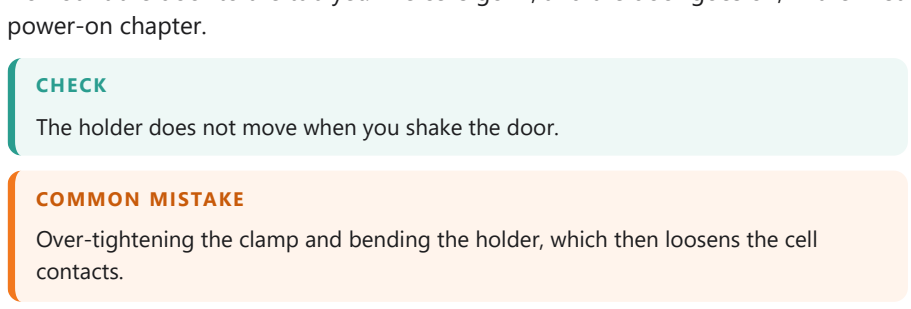
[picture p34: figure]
power-on chapter.; CHECK; COMMON MISTAKE; contacts.

The holder does not move when you shake the door.

Over-tightening the clamp and bending the holder, which then loosens the cell

## A9 Side panels on

left and right side panels (no screws)

Each side panel covers the two hip servos on its side. It has four snap hooks and no

Hold the panel so its two round holes line up with the round bosses of the hip servos, then press it straight onto the wall until all four hooks click. Do the left panel on the left, the right panel on the right: the slot for the leg leads is at the top of each round hole.
Fit the side panels before the legs, because the thigh cups help hold the panels in

The panel sits flush all round, and each servo boss is centred in its round hole.

Pressing on one end only. Press both ends together, or a hook can break off.

SECTION B

# B Lid

The lid is built on its own, upside down on the table. It carries the motion sensor, the touch board, the power hub, the two side lasers, the tail servo and four touch pads, and the collar screws on top of it.

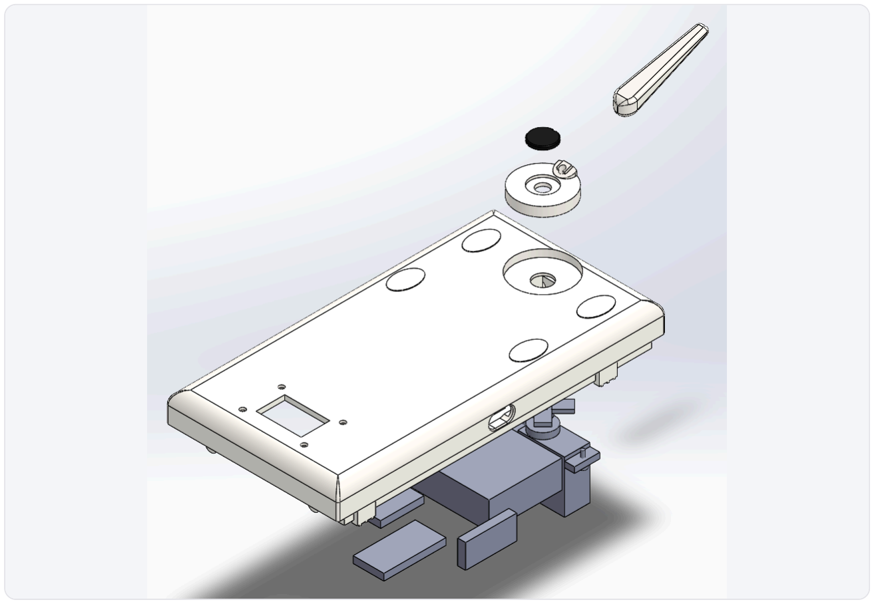
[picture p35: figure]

## B1 Get to know the lid (underside)

The lid carries the motion sensor, the touch board, the power hub, the tail servo, the two side lasers and four touch pads. Turn it upside down and find each place. Clean the print and pre-thread the holes you will use in this chapter: the tail servo pilots, the four touch pad pilots and the four collar holes.

CHECK
The lid's top edge is smooth. If the first millimetre drooped while printing, sand it lightly (Printing, note A).

COMMON MISTAKE
Pre-threading the touch pad holes with an M2x6. It is too long and comes out through the top. Use an M2x4.

## B2 Motion sensor and touch board

MPR121 touch board
foam tape

Both boards sit in their own fences on the underside of the lid, components facing

Stick each one in with foam tape. The motion sensor must sit flat and square in its fence, because the robot uses it to know which way is up.

Neither board can rock. The motion sensor's edges are parallel to the fence.

Mounting the motion sensor at an angle. It then thinks the robot is always leaning.

## B3 Power hub under the lid

the hub you built in Wiring step 4.5
2 cable ties

The hub carries the two 5 V power modules, the two big capacitors and the small resistors. It fits in the large fence towards the back of the lid.
Press it in, components facing down, and pass one cable tie under each pair of anchors beside the fence. Pull them snug, not tight, and snip the tails.

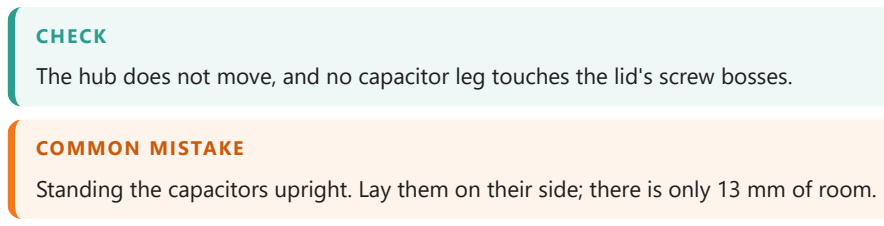
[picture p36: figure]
CHECK; COMMON MISTAKE

The hub does not move, and no capacitor leg touches the lid's screw bosses.

Standing the capacitors upright. Lay them on their side; there is only 13 mm of room.

## B4 Two side lasers

foam tape

One laser stands on a shelf against each side wall of the lid, looking sideways

Peel the film off the chip, slide the board down behind the lip on its two posts, chip facing the window, and fix it with a small square of foam tape.

From outside you can see the chip through the window.

Fitting the board chip-inward. The chip must face the window.

## B5 Tail servo

flagged TAIL

### 2 x M2 x 6

The tail servo hangs under two ribs near the back of the lid, with its output shaft

Hold the servo under the ribs with its tabs against them and drive 2 x M2x6 up through the tabs from inside the lid.

Look at the lid from the top: the servo spline sits in the middle of the tail socket.

Fitting the servo with its shaft at the wrong end. The shaft must be under the socket,

## B6 Four foil touch pads

kitchen foil, 4 pieces about 25 x 20 mm
4 grey wires from the touch board

### 4 x M2 x 4

The robot feels petting through four foil pads on the inside of the lid, under the

Cut a foil piece with a small tab, poke a hole in the tab, and lay it on the inside of the lid under an oval. Strip 5 mm of its wire, wrap the bare end once round an M2x4 screw, and drive the screw through the foil tab into the pad hole so the wire and foil are clamped together.
A dot of superglue at each corner keeps the foil flat. Wire E0 to E3 as the labels

With the multimeter on beeper mode, each wire beeps to its foil.

Using an M2x6 here. It comes out through the top of the lid.

## B7 Collar onto the lid

### 4 x M2 x 8

Before you fit the collar, feed the head's leads up from the hub through the lid's neck opening: the screen power lead, the screen sensor lead (port P4), the camera power lead, the gesture sensor lead and the head touch pad wire. Leave about 15 cm sticking out.
Set the collar on the lid, leads through its middle, and screw it on from inside the

The collar sits flat all round, and every head lead comes out of its top.

Fitting the collar first and then trying to push plugs through it. Feed the leads first.

SECTION C

# C Head

The head holds the screen, the microphones, the speaker, the camera and the gesture sensor. It is built on the table, then screwed onto the collar on the lid. The head back stays off until the very end.

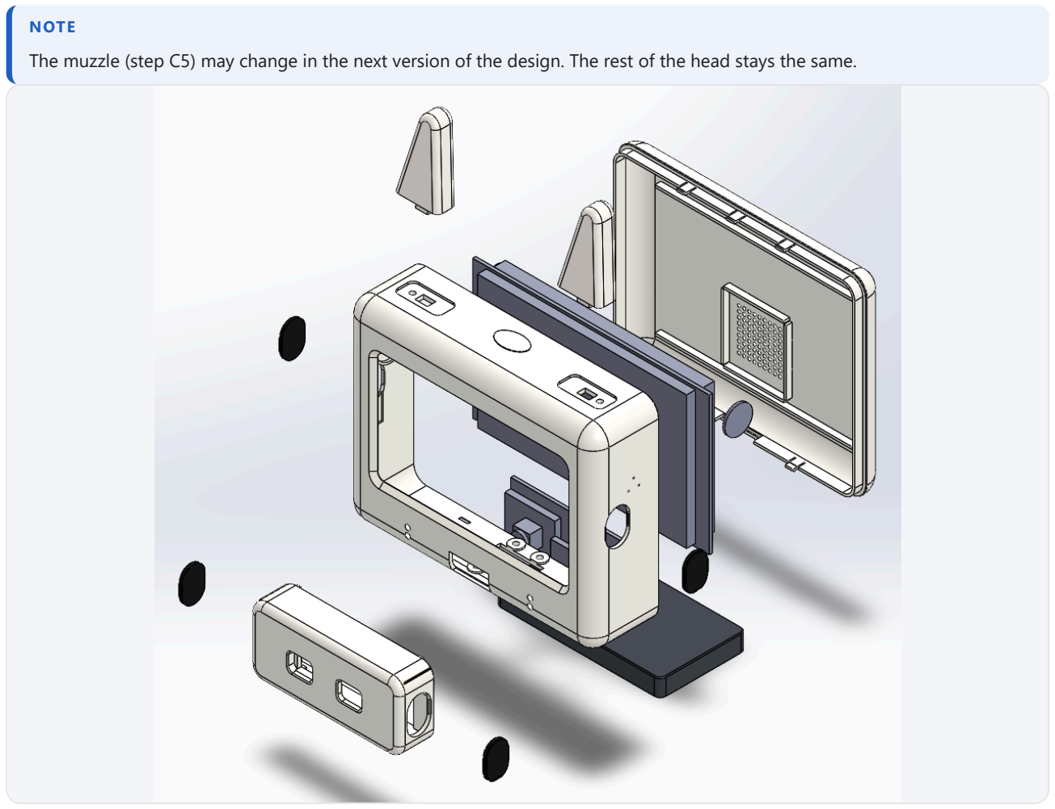
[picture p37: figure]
NOTE

The muzzle (step C5) may change in the next version of the design. The rest of the head stays the same.

## C1 Get to know the head front (inside)

The head front holds the screen, both microphones, the head touch pad and the ears, and the muzzle and collar screw to it from inside. Look inside it and find each

Pre-thread the four screen bosses with an M2x6, then take the screw out again.

CHECK
The screen window's bevel is clean and the glass seat (the flat ledge round the window) has no blobs.

COMMON MISTAKE
Leaving support or brim blobs on the glass seat. The screen then sits crooked and can crack when you screw it down.

## C2 Screen into the head front

(tested)
4 printed screen washers

### 4 x M2 x 6

Lay the head front face down on a soft cloth. Put the screen board in, glass first, so the glass sits on the ledge round the window. The board's USB-C socket must face the robot's right side (your left as you look into the back of the head), next to the port door opening.
Put a printed washer over each of the four corner holes and drive 1 x M2x6 through each into the bosses. Tighten in a cross pattern, and stop as soon as each screw is snug.
Plug the 5 V lead into port P1 and the sensor lead into port P4 now, while you can still reach them.

CHECK
Turn the head over: the picture area sits evenly in the window, with no gap at any edge.

COMMON MISTAKE
Over-tightening a corner screw. The glass is bonded to the board and cracks if the board bends.

## C3 Microphones

(Wiring, S11 and S12)
superglue

Each microphone sits in the round ring on the inside of a side wall, with its sound hole facing the three tiny holes in the wall.
Put a very small drop of superglue on the ring's rim, not near the holes, and press the microphone in, sound hole outward. Hold it for 20 seconds.
The left microphone is the one with its L/R pin wired to GND.

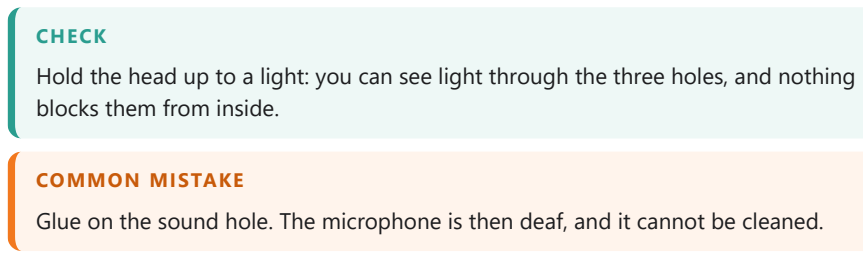
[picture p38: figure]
CHECK; blocks them from inside.; COMMON MISTAKE

Hold the head up to a light: you can see light through the three holes, and nothing

Glue on the sound hole. The microphone is then deaf, and it cannot be cleaned.

## C4 Head touch pad and port doors

foil piece about 20 x 15 mm and its grey wire (MPR121 E4)

### 1 x M2 x 4

4 black port doors and blanks

Head touch pad: lay the foil under the raised oval on the inside of the head's top, wrap the stripped wire end round an M2x4, and drive it through the foil tab into the pad hole, exactly as for the lid pads.
Port doors: the door with the finger notch covers a USB-C socket and the plain blank matches it on the other side, so the head looks the same from both sides. Press the head door into the opening on the robot's right side, and the head blank into the left. The muzzle door goes on the robot's left of the muzzle and its blank

Each door clicks in flush and comes out again with a fingernail in the notch.

Using an M2x6 for the touch pad: it comes through the top of the head.

## C5 Muzzle: camera and gesture sensor

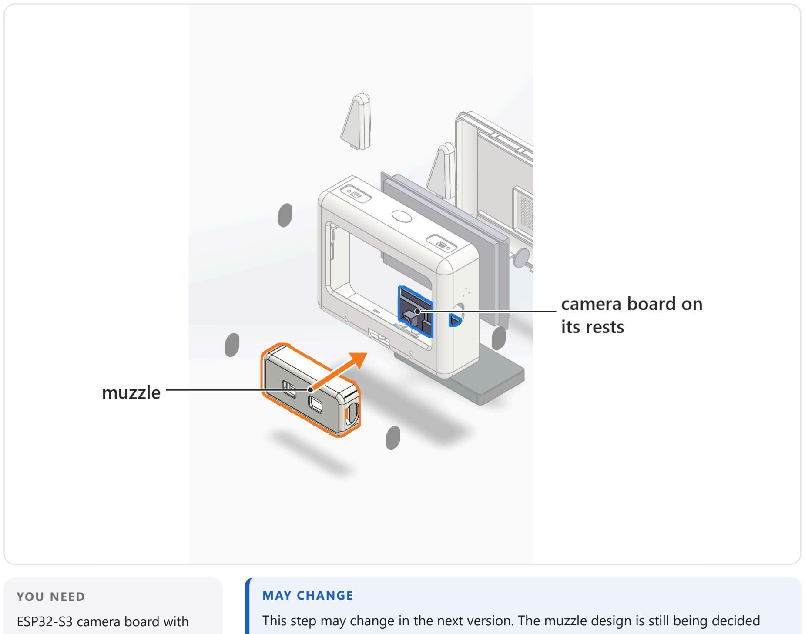
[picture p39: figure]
YOU NEED ESP32-S3 camera board with; MAY CHANGE

OV5640 (tested)
APDS-9960 gesture sensor
foam tape

### 4 x M2 x 8

This step may change in the next version. The muzzle design is still being decided (the current muzzle, a forehead camera above the screen, a camera in a collar tag, or a smooth chin, since the screen already draws a mouth). Build it as shown here for

Stand the camera board on the muzzle floor, against its rests, with the camera lens pushed into the square pocket behind the window on the robot's right (your left as you face the robot). Its USB-C socket then faces the muzzle port door.
Stand the gesture sensor on its shelf behind the other window, chip centred in the window, and fix it with a small square of foam tape.
Plug the camera board's 5 V lead and the gesture sensor lead, feed them through the hole in the head's face, then hold the muzzle against the head and drive 4 x M2x8 from inside the head into the muzzle.

Look into the muzzle windows from the front: you see the lens in one and the sensor

Pinching the thin camera ribbon. Fold it gently; a sharp crease breaks it.

## C6 Head onto the collar

the lid with the collar fitted (step B7)

### 4 x M2 x 8

Feed the head leads that stick out of the collar up through the hole in the head's

Sit the head on the collar and drive 4 x M2x8 down through the head floor into the collar, from inside the head.
Connect the leads: 5 V to P1 and the sensor lead to P4 if you have not already, the gesture sensor lead to its row, and the head touch pad wire to the touch board

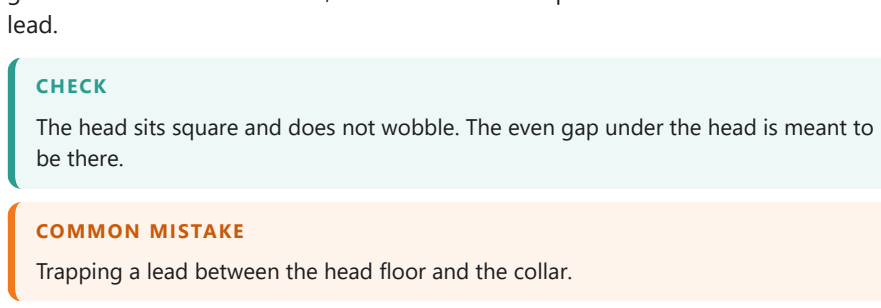
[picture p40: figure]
lead.; CHECK; be there.; COMMON MISTAKE

The head sits square and does not wobble. The even gap under the head is meant to

Trapping a lead between the head floor and the collar.

## C7 Speaker into the head back

3 W speaker with its 1.25 mm plug

The speaker sits in the fences on the inside of the head back, facing the grille of

Press it in, plug its lead into the screen board's "Speak" port, and put the head back aside. It clips on at the very end (step G4), after the ears are fitted.

The speaker cannot rattle in its fences.

Clipping the head back on now. You still need to reach inside the head for the ears.

SECTION D

# D Legs

Each leg is a thigh and a shin, each made of an outer half and a cover, plus a wheel. It carries the knee servo and the wheel servo, and hangs on the hip servo in the tub. All the leads run inside the leg. Build one leg all the way, then the

## D1 Which leg is which

for each leg: thigh outer + cover, shin outer + cover, wheel, 3 caps
per leg: 2 MG90S 180 (knee) and 1 MG90S 360 (wheel), all centred

The four legs are built the same way. The pictures in this chapter show the frontleft leg; build the other three the same.
Each printed file has its leg in the name, for example Thigh_FrontLeft_Outer. Some shapes are identical, so if you mix two up nothing is lost: the front-left and backright thighs are the same shape turned round, and so are the front-right and backleft. The two left shins match, the two right shins match, and all four wheels match. The knee servo body always points away from the middle of the robot: forward on the front legs, backward on the back legs. Every paw (the wheel servo body) points

Lay out the four sets on the table in the shape of the robot before you start.

Mixing a left shin with a right leg. Left and right shins are mirror images and do not fit

## D2 Hip horn into the thigh

a 4-arm cross horn from a servo bag
2.0 mm drill bit (turned by hand)

### 2 x M2 x 4

The holes in the servo horns are about 1.5 mm, too small for an M2 screw. Pick the two opposite arms you will use and open one hole on each to 2 mm by turning the drill bit between your fingers. Use holes between 6.7 and 10 mm from the horn's centre.
Lay the horn in the cross-shaped pocket on the inside face of the thigh, at the hip end, with its hub facing out of the pocket, and drive 1 x M2x4 through each

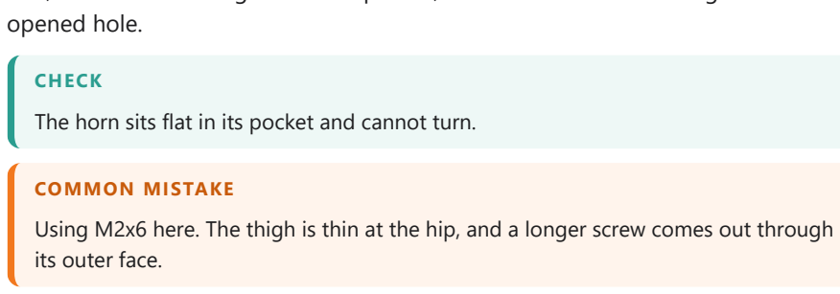
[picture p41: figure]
opened hole.; CHECK; COMMON MISTAKE; its outer face.

The horn sits flat in its pocket and cannot turn.

Using M2x6 here. The thigh is thin at the hip, and a longer screw comes out through

## D3 Knee servo onto the thigh

flagged K + leg name

### 2 x M2 x 6

Set the knee servo onto the knee end of the thigh outer half, tabs flat on the face, with the round output boss in the round bore. Its body points away from the middle of the robot: forward on a front leg, backward on a back leg.
Fix it with 2 x M2x6 through the tabs into the blind holes. The knee servo's lead leaves the body at the end nearest the knee.

CHECK
The servo spline sits in the middle of the bore and the tabs touch the face all the way along.

COMMON MISTAKE
Turning the servo round so its body points toward the robot's middle. It will then hit the belly when the leg swings.

## D4 Knee horn and wheel servo onto the shin

cross horn (two holes opened to 2 mm)
MG90S 360, lead flagged W + leg name

### 4 x M2 x 6

At the knee end of the shin outer half there is a cross-shaped pocket, just like the thigh's. Lay a horn in it, hub facing out, and fix it with 2 x M2x6.
At the paw end, set the wheel servo (the 360 degree one) with its tabs on the face and its round boss in the bore, body pointing forward on every leg. Fix it with 2 x M2x6.

CHECK
Both screws of each pair are the same length. The knee horn screws here are M2x6, unlike the thigh.

COMMON MISTAKE
Fitting a 180 degree servo in the paw. The wheel servos are the 360 degree ones from the pack of four.

## D5 Horn into the wheel

cross horn (two OUTER holes opened to 2 mm)

### 2 x M2 x 6

Lay a horn in the cross-shaped pocket on the inner face of the wheel, hub facing out, and fix it with 2 x M2x6 through the outer holes, at least 7.6 mm from the

Put the wheel aside for now. It goes on after the shin cover.

Using the inner horn holes. The screw then misses the thicker part of the wheel.

## D6 Shin cover, with the wheel lead inside

### 1 x M2 x 8

The wheel servo's lead runs up the inside of the shin to the knee. Lay it in the channel along the shin outer half, and bring it out through the window in the cover's knee ring at 6 o'clock (the bottom of the ring).
Slide the cover's tongue into the knee ring, then press the cover onto the shin until both snap hooks click. The paw pod closes round the wheel servo body.
Drive 1 x M2x8 into the hole in the outer face, under where the wheel will sit.

CHECK
No part of the lead shows along the shin, and about 20 cm of it comes out of the knee ring window.

COMMON MISTAKE
Trapping the lead under the cover's edge. If the cover does not close with a gentle press, open it and re-lay the lead.

## D7 Join the knee (lead half a turn round)

thigh with knee servo (D3), shin with cover (D6)
servo's own horn screw
12 mm black knee cap

Hold the thigh and the shin side by side. Pass the wheel lead from the knee ring window half a turn round the knee, then in through the small hole at 12 o'clock in the thigh face. This loose half turn is what lets the knee bend without pulling the lead.
Check the knee servo is still centred. Hold the leg straight, thigh and shin in one line, and push the shin's knee horn onto the knee servo spline.
Drive the servo's own horn screw through the 6 mm hole in the shin's outer face into the spline. Press the 12 mm cap into its recess, with the cap's small notch at the bottom so you can prise it out later.

CHECK
Bend the knee gently to about half way both ways: the lead slides round freely and never tightens.

COMMON MISTAKE
Fitting the horn one tooth off. If the leg is not straight with the servo centred, pull the shin off and move it one tooth.

## D8 Thigh cover, both leads inside

### 1 x M2 x 8

Now two leads run up the thigh: the knee servo's own lead, from the end of its body nearest the knee, and the wheel lead coming out of the 12 o'clock hole. Lay both in the channel up the thigh, into the hip cup, and out through the cup's window at 6 o'clock.
Slide the cover's tongue into the window at the bottom of the hip cup and press the cover on until both hooks click. The knee pod closes round the knee servo body.
Drive 1 x M2x8 into the hole in the outer face at the bottom of the knee disc. The

Both leads come out of the hip cup, and each is at least 20 cm long from there.

Cutting or shortening a lead. The wheel lead needs about 200 mm to reach the servo

## D9 Wheel and tyre

horn screw
14 mm black wheel cap
O-ring, the 31 mm outside-diameter size from the
assortment (about 26.2 mm
inside, 2.4 mm thick)

Push the wheel's horn onto the wheel servo spline. The wheel servo turns all the way round, so there is no "centre" to find here.
Drive the horn screw through the centre hole and press the 14 mm cap in, notch at the bottom.
Pick a 31 mm outside-diameter ring from the O-ring assortment (about 26.2 mm inside, 2.4 mm thick). Stretch it into the groove round the wheel. It should sit snug without twisting, and only about 1 mm of it should show above the rims, like a tread. Check the fit on the first wheel before you do the other three.

CHECK
Spin the wheel by hand: it turns smoothly, the tyre does not wobble, and no part of the rim touches the desk.

COMMON MISTAKE
Taking the wrong size from the assortment. A ring one size smaller is too tight and rolls; one size bigger falls off. Use the 31 mm outside-diameter rings.

## D10 Leg onto the body

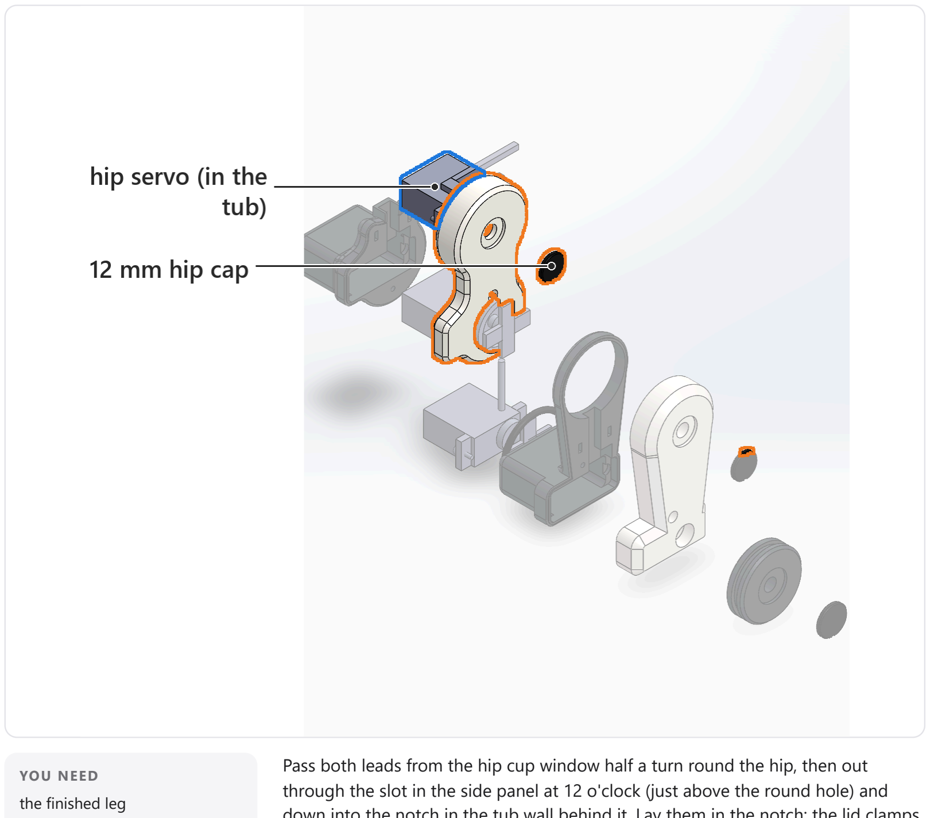
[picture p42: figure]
YOU NEED the finished leg

horn screw
12 mm black hip cap

Pass both leads from the hip cup window half a turn round the hip, then out through the slot in the side panel at 12 o'clock (just above the round hole) and down into the notch in the tub wall behind it. Lay them in the notch; the lid clamps them later.
Check the hip servo is centred. Hold the leg straight down and push the thigh's hip horn onto the hip servo spline.
Drive the horn screw through the 6 mm hole in the thigh's outer face, and press the 12 mm cap in, notch at the bottom.

CHECK
Swing the leg gently forward and back by about 30 degrees: the leads move freely in the cup and nothing rubs.

COMMON MISTAKE
Threading the leads through a closed hole. The tub notch is open at the top on purpose: lay them in from above.

## D11 Range check and joint limits

Before the lid goes on, move every joint through its whole range by hand, slowly: each hip about 30 degrees forward and back, each knee about 50 degrees both ways. Watch the leads in each hip cup and at each knee. Nothing may pinch, rub or pull tight.
Angles count from the straight-down pose. Plus moves the foot forward, toward the head, and minus moves it back. The hip angle turns the thigh; the knee angle turns the shin relative to the thigh. The left and right legs are mirror images, so the firmware maps these angles to each servo's own direction.
Front legs need no limit inside hip plus or minus 30 and knee plus or minus 50 degrees. Back legs: when the hip is above plus 25 degrees, keep the knee at or below plus 45 degrees. At hip plus 30 and knee plus 50 the back paw would come within 0.9 mm of the belly; with this rule the gap never drops below 4.6 mm. Walking never gets near these poses. They only matter for tricks like sitting or

Every joint moves by hand without catching, and every lead still lies in its channel.

Forcing a joint past a stop. Servo gears strip if you lean on them.

SECTION E

# E Tail

The tail is a root that turns in the socket on top of the lid, with the tail keyed onto it.

## E1 Fit the tail

tail root, tail, 12 mm black tail cap
cross horn (two holes opened to 2 mm)

### 2 x M2 x 4 1 x M2 x 8

horn screw

Lay a horn in the pocket under the tail root and fix it with 2 x M2x4. The root is only 4.6 mm thick, so nothing longer.
Key the tail onto the root and fix it with 1 x M2x8 driven up from under the root. Do this before the root goes on the servo, because you cannot reach the screw afterwards.
Check the tail servo is centred. Push the root into the round socket on top of the lid, horn onto the spline, with the tail pointing straight back. Drive the horn screw through the centre and press the cap in.

CHECK
The tail can swing a little both ways by hand and the root turns without rubbing the socket.

COMMON MISTAKE
Fitting the tail to the root after the root is on the servo. The tail screw is then out of reach.

SECTION F

## F Ears

## F1 Fit the ears

### 2 x M2 x 8

Each ear has a keyed peg that fits one way only into its pocket on top of the head.

Push each ear into its pocket, then reach inside the head and drive 1 x M2x8 up through the pad under the pocket into the ear.

Forcing an ear into the wrong pocket. If the peg does not drop in, try the other ear.

SECTION G

# G Close up

Everything is built. Now every lead is connected, the lid with the head goes onto the tub, and the bands and the head back snap on.

## G1 Connect every lead

servo channels, lasers
cable ties

With the lid standing on its side next to the tub, connect everything, one table row at a time, and tick each row off in the Wiring chapter.
Servo leads: each plugs into its channel on the servo board on its own side (servo channel table), with the brown wire on the GND row at the bottom of the header and the orange wire on the PWM row at the top. The tail servo goes to board A, channel 8.
Laser XSHUT wires go to board B, channels 9 to 15. Power and sensor leads from the tub go to the hub under the lid. Leave each tub-to-lid lead about 10 cm longer than it needs to be, so the lid can stand beside the tub while you work.
Tie slack loops with small cable ties, away from the servo horns and from the battery door opening.

CHECK
Go through every table row once more with a finger on each plug. Every plug is fully home and no pin shows.

COMMON MISTAKE
Plugging a servo lead in upside down. The servo then does nothing; it is not damaged, just turn the plug round.

## G2 Lid onto the tub

Check that every hip lead lies flat in its notch at the top of the tub wall, and that no lead crosses the tub's top edge anywhere else.
Lower the lid straight down onto the tub. Its lip slides inside the tub wall and its combs press the leads into the notches.
Drive 2 x M2x6 through the chest wall and 2 x M2x6 through the rump wall into the

The seam between lid and tub is even all round, and the lid does not rock.

Closing the lid on a lead. If it does not sit down with a light press, lift it and find the

## G3 Chest and rump bands

chest band and rump band (no screws)

The bands hide the four lid screws. Each has two snap hooks.
Press the chest band into its recess on the front of the tub, laser window over the front laser, until both hooks click. Do the same with the rump band at the back; its larger pill-shaped opening goes over the USB-C socket.

Plug the USB-C cable in through the rump band: it goes fully home.

Putting the bands on the wrong ends. The rump band is the one with the USB-C

## G4 Head back on

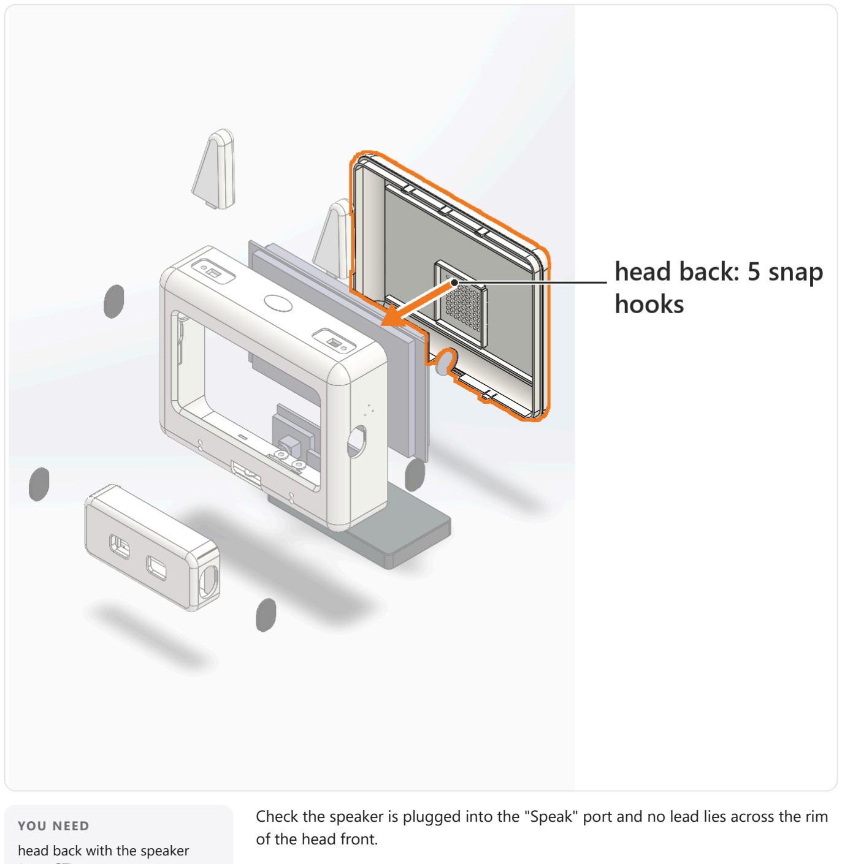
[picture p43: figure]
YOU NEED head back with the speaker; of the head front.

(step C7)

Check the speaker is plugged into the "Speak" port and no lead lies across the rim

Slide the head back's lip into the head front and press until all five hooks click: three along the top and two along the bottom.

The groove between the two halves is even all round.

Squeezing a lead in the rim. The head back then will not sit flush; do not force it.

7
CHAPTER 7

# First power-on and calibration

The cells go in, the battery door goes on, and the robot is switched on for the first time on a block, with the servo test sketch still in the screen board. Then every servo gets its small correction, written into the table at the end of this chapter.

## 7.1 Checks before the cells go in

a block or mug to prop the robot on

Set the power switch to OFF. Set the multimeter to its beeper (continuity) mode. Touch the probes to the protection board's P+ and P- pads: it must not beep. Then to the output of each 5 V module on the hub: it must not beep. A beep means a short circuit. Find it before you go on.
Stand the robot on a block so all four wheels are off the desk. It stays there for

No beep on any power pair, and the fuse is in its holder.

Testing with the cells in. The beeper test is only safe with the power off and the cells

## 7.2 Cells in, protection board awake

USB-C charger and cable

Measure each cell with the multimeter on DC volts. Each should read between 3.0 and 4.2 V, and the two must be within 0.05 V of each other. If not, charge them separately or use the spare pair; never mix a Samsung with a Tinker cell.
Check the + and - marks in the holder twice. Put in first the cell that sits between the black lead and the middle wire, then the other one. This connects negative, then the middle, then positive, in the order the protection board needs.
Plug the USB-C charger into the rump socket for a few seconds and unplug it. This wakes the protection board. Now measure between P+ and P-: you should see the two cell voltages added together, between 6.0 and 8.4 V.

The two cells are the same model, the same charge, and the right way round.

Reading 0 V at P+ and P-. The protection board is still asleep: plug the charger in

## 7.3 Battery door on

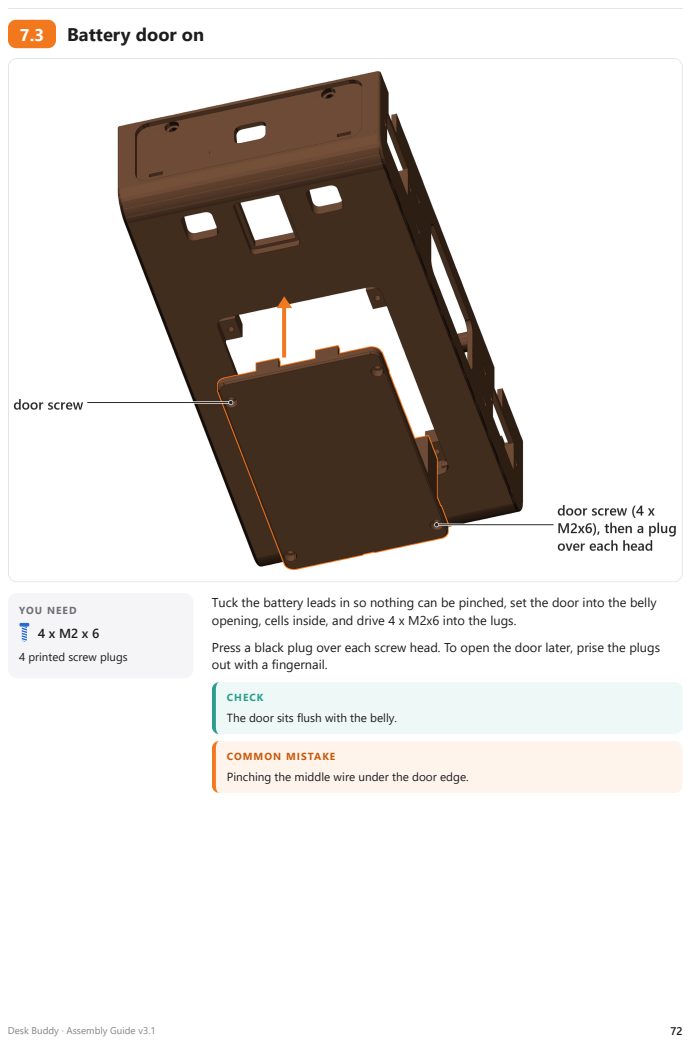
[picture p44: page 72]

YOU NEED
4 printed screw plugs

Tuck the battery leads in so nothing can be pinched, set the door into the belly
opening, cells inside, and drive 4 x M2x6 into the lugs.
Press a black plug over each screw head. To open the door later, prise the plugs
out with a fingernail.

CHECK
The door sits flush with the belly.

COMMON MISTAKE
Pinching the middle wire under the door edge.

## 7.4 First switch-on

(tools/servo_center)
USB-C data cable

For the first switch-on the screen board runs the servo sketch from the Bench test chapter. Unplug the 5 V lead from port P1 (the rule: never two power sources on one board), then connect the laptop to the screen board's USB-C socket behind the head port door. The laptop now powers the screen board; the battery powers the servos.
Open the Serial Monitor (pio device monitor) and switch the robot on. Within two seconds every leg should stiffen with the legs straight and the tail straight back, and the wheels should stay still or creep slowly.
Type s and press Enter. The list must show 0x40 and 0x41 (both servo boards), 0x39 (gesture), 0x5A (touch) and 0x68 (motion). Type l to check all seven lasers answer one by one, and v to read the battery voltage.

All thirteen servos hold still, nothing gets hot, and the battery reading matches the

Leaving P1 plugged in while the USB cable is in.

## 7.5 If something does not move

Switch off first, every time, before you touch a plug.
One servo limp: its plug is on the wrong channel, on the wrong board, or upside down. Check the servo channel table; the brown wire goes on the GND row.
Every servo limp: the servo boards are not getting 5 V, or the wheel-stop line is high. Measure between V+ and GND on each board's green terminal: it must read about 5 V. Then check the green OE wire goes to IO14 and the 2.2 kOhm resistor goes to 3.3 V, not to 5 V. Type c in the Serial Monitor to switch the outputs on again.
A servo board "NOT FOUND": check its VCC reads 3.3 V, its SDA and SCL go to the right rails, and, for board B, that the A0 pad is bridged.
A wheel keeps turning: it is normal for a 360 degree servo to creep at 1500 us. Find its real stop point in the next step.

## 7.6 Calibrate every servo

YOU NEED
the calibration table in this step
a pencil

A horn fits on its spline only in steps of one tooth, so a leg that looks almost straight is normal. The firmware corrects the last few degrees with a trim for each servo, and this step finds those trims.
In the Serial Monitor press n until the servo you want is selected (it wiggles). Press + or - to move it 10 us at a time until the leg is exactly straight, or the tail exactly straight back. Write the number in the table.
For each wheel, press + or - until the wheel stops completely, and write that number down as its stop point.
Finally, for each hip and knee, check which way plus moves it. Plus must move the foot forward, toward the head. If it moves back, write "reversed" in the table. The left and right legs are usually opposite.
Before long walks, check how hot the knee pods get with the multimeter's thermocouple, if it has one: stop and let the robot cool above 45 degrees C.

CHECK
Every row of the table has a number.

## 7.7 Charging and everyday care

YOU NEED
5 V, 2 A phone charger with a
USB-A to USB-C cable

Switch the robot off, then plug the charger into the USB-C socket in the rump band. The robot cannot run while it charges.
The firmware warns at 7.0 V and at 6.8 V parks the robot and switches the servos off. Charge it then; running the cells flatter shortens their life.
To take the cells out, switch off, prise out the four plugs under the belly, and undo the four door screws. Always swap both cells together.

## 7.8 Calibration table

Fill in a number for every servo. The robot firmware reads these values; keep this page with the robot.

Servo | Board / channel | Centre or straight (us) | Wheel stop (us) | + moves the foot forward? (yes / reversed)
Hip, front-left | A / 0 | | —
Knee, front-left | A / 1 | | —
Wheel, front-left (360) | A / 2 | | | —
Hip, back-left | A / 4 | | —
Knee, back-left | A / 5 | | —
Wheel, back-left (360) | A / 6 | | | —
Tail | A / 8 | | —
Hip, front-right | B / 0 | | —
Knee, front-right | B / 1 | | —
Wheel, front-right (360) | B / 2 | | | —
Hip, back-right | B / 4 | | —
Knee, back-right | B / 5 | | —
Wheel, back-right (360) | B / 6 | | | —

8
CHAPTER 8

# Troubleshooting

Find the symptom, check the likely cause, then do the fix. Switch the robot off before you touch any wire, every time.

Nothing happens when I switch on.
Likely cause: The protection board is asleep, the fuse has blown, or a cell is in the wrong way round.
Fix: Switch off. Measure P+ to P- at the protection board: 0 V means it is asleep, so plug the USB-C charger in for a few seconds. If it still reads 0 V, check the fuse and the cells' + and - marks.

The fuse blows as soon as I switch on.
Likely cause: A short circuit after the fuse: a bare wire end, a solder blob, or a screw tip touching a board.
Fix: Take the fuse out. With the multimeter on beeper mode, test the switched battery wire to GND, then each 5 V module output to GND. Look for the joint that beeps and fix it before you fit a new fuse.

The screen board restarts when the legs move. Likely cause: The servos pull the 5 V line down. Either the two 5 V modules are sharing a job, or a capacitor is missing. Fix: Check that module #1 feeds only the servo boards and module #2 only the screen and camera boards, and that each has its 1000 uF capacitor, stripe to minus.

The screen board restarts when the lasers start up. Likely cause: Seven lasers plus the other sensors ask too much of the screen board's 3.3 V supply.
Fix: Measure the 3.3 V rail while it happens. If it dips below 3.1 V, move the lasers' VIN to the 5 V boards rail, but only after checking that each laser's SDA and SCL pins still read 3.3 V or less. Otherwise add a separate 3.3 V module.

One servo does nothing.
Likely cause: Its plug is on the wrong channel or board, or upside down.
Fix: Check the servo channel table. The brown wire goes on the GND row. Use the servo sketch: press n until that servo is selected and watch whether it wiggles.

Every servo is limp.
Likely cause: No 5 V on the servo boards' green terminal, or the wheel-stop (OE) line is high.
Fix: Measure V+ to GND on each green terminal: about 5 V. Then check the green OE wire goes to IO14 and the 2.2 kOhm resistor goes to 3.3 V. In the servo sketch, press c.

A servo board is "NOT FOUND".
Likely cause: No 3.3 V on its VCC pin, SDA and SCL swapped or loose, or (board B) the A0 pad is not bridged.
Fix: Measure 3.3 V on VCC. Re-seat the SDA and SCL wires. Board B must show 0x41 in the scan; if both boards show as 0x40, bridge A0 on board B.

A wheel keeps creeping when it should stop. Likely cause: Every 360 degree servo has its own stop point, a little away from 1500 us.
Fix: Find the stop point with + and - in the servo sketch and write it in the calibration table. The firmware uses that number.

A leg is not straight when its servo is centred. Likely cause: The horn went onto the spline one tooth off, or the servo was turned by hand after centring.
Fix: Small errors are fixed with the trim in the calibration table. If the error is bigger than about half a tooth, take the horn screw out, lift the horn off, and refit it one tooth over.

A servo buzzes or gets warm while standing still. Likely cause: It is pushing against a stop: a lead is pinched, a part rubs, or its trim asks for a pose it cannot reach.
Fix: Switch off, move the joint by hand to find what catches, and re-lay any lead. Check the joint limits for the back legs.

A laser reads a short distance all the time.
Likely cause: The protective film is still on the chip, or the

Fix: Peel the film off. Re-seat the board so the chip sits in the middle of the window, and keep the window clean.

Only one laser answers, or none.
Likely cause: All seven lasers start at the same address. The firmware wakes them one by one using the XSHUT wires. Fix: Run l in the servo sketch. A laser that shows NO ANSWER has a loose XSHUT, SDA, SCL, VIN or GND wire, or its XSHUT is on the wrong channel of board B.

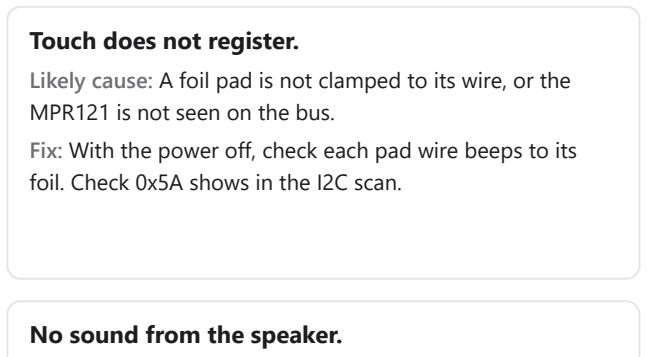
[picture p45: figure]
Touch does not register.; MPR121 is not seen on the bus.; foil. Check 0x5A shows in the I2C scan.; No sound from the speaker.

Likely cause: A foil pad is not clamped to its wire, or the

Fix: With the power off, check each pad wire beeps to its

The microphones hear nothing, or left and right are swapped.
Likely cause: Glue over the sound holes, a wrong pin on P3, or both mics with the same L/R setting.
Fix: Check the sound holes are open. One mic's L/R pin goes to GND and the other's to 3.3 V. Check the three data lines against the signal table.

Likely cause: The speaker is not in the "Speak" port, or a

Fix: Plug it into "Speak" only. Never connect either speaker

The laptop cannot find the board, or the upload fails.
Likely cause: A charge-only USB cable, or the board is also powered through P1.
Fix: Unplug the 5 V lead from P1 first. Try the phone cable test from the parts check: if the phone does not show up on the laptop, the cable is charge-only. Hold BOOT while you plug the cable in to force upload mode.

The Serial Monitor stays empty after an upload. Likely cause: The screen board's USB-C goes to the chip's own USB port, not to a USB-serial chip.
Fix: In tools/servo_center/platformio.ini change ARDUINO_USB_CDC_ON_BOOT=0 to 1, upload again, and reopen the monitor.

Likely cause: A lead is trapped under its edge, or a print

Fix: Never force it. Open it, re-lay the lead in its channel, and clean the hook windows with the flush cutters.

A screw spins without tightening.
Likely cause: The pilot hole is stripped.
Fix: Take the screw out, put a drop of superglue in the hole, let it set for ten minutes, and drive the screw in gently. A heat-set insert is the long-term fix for covers you open often.

Likely cause: The knees work hard when the robot stands for a long time, and the pods are closed plastic.
Fix: Check with a thermocouple. Stop and let the robot cool above 45 degrees C. Let it sit or lie down between walks.

The robot tips when it lifts a foot.
Likely cause: The weight is not where the design expects: a heavy item moved, or the cells are different.
Fix: Check the hub and the battery sit in their fences. The firmware shifts the body about 8 mm before lifting a front foot; do not lift a foot without that shift.

Likely cause: Old or mismatched cells, or the servos hold a

Fix: Charge both cells fully, check they are within 0.05 V, and look for a buzzing servo. Use the spare pair to compare.

9
CHAPTER 9

# Appendix

## 9.1 Bought parts, with store listings

What was bought for this build (shopping list of 26 September 2026). The links go to the listing each part was ordered from; seller photos are not reproduced here.

1 | Head front, behind the screen window | AliExpress
1 | Muzzle (lens in the left window) | AliExpress
10 | 4 hips, 4 knees, tail, 1 spare | AliExpress
PCA9685 16-channel servo board | 2 | Tub, one on each side wall | AliExpress
VL53L0X laser distance sensor | 8 | 7 fitted (chest, rump, 3 desk-edge in the tub
MS3625 I2S microphone | 2 | Mic rings on each side of the head front | AliExpress
MPU6050 motion sensor (GY-521) | 1 | Under the lid, in its fence | AliExpress
APDS-9960 gesture sensor | 1 | Muzzle, on its shelf behind the right window | AliExpress
MPR121 touch board | 1 | Under the lid, in its fence | AliExpress
Type-C 2S boost charging board | 1 | Tub, raised ledge at the rump; socket in the
| 2 | On the perfboard hub under the lid | AliExpress
KCD1 rocker switch | 1 | Front of the belly, flush in its recess | AliExpress

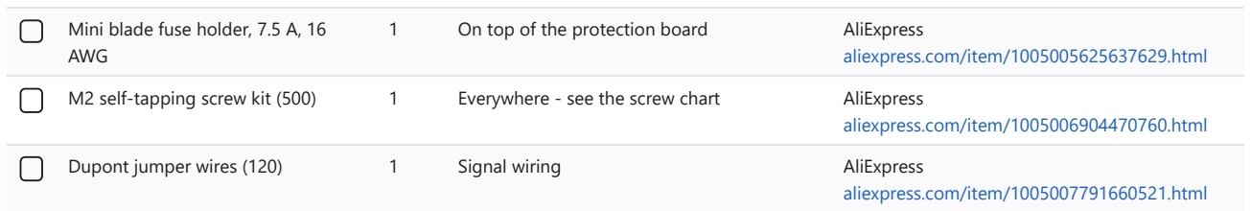
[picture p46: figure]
Mini blade fuse holder, 7.5 A, 16 AWG; aliexpress.com/item/1005005625637629.html; aliexpress.com/item/1005006904470760.html; Dupont jumper wires (120); Signal wiring; AliExpress; aliexpress.com/item/1005007791660521.html

| 1 | On top of the protection board | AliExpress
M2 self-tapping screw kit (500) | 1 | Everywhere - see the screw chart | AliExpress
MX1.25 4-pin pre-wired plugs (10) | 1 | Plugs for the screen board ports P1, P3, P4 | AliExpress

Part | Qty | Where it goes | Store and listing
Perfboard 5 x 7 cm (5) | 1 | The power and sensor hub under the lid | AliExpress aliexpress.com/item/1005007024264426.html
3M double-sided foam tape, 20 mm | 1 | Sensor boards and the hub | AliExpress aliexpress.com/item/1005007010049062.html
Heat-shrink tubing (127) | 1 | Every soldered joint | AliExpress aliexpress.com/item/1005008728485990.html
830-point breadboard | 1 | Tool: bench test | AliExpress aliexpress.com/item/1005007345339483.html
ES02 soldering kit + digital multimeter | 1 | Tool | AliExpress aliexpress.com/item/1005007170830774.html
PLATO 170 flush cutters | 1 | Tool | AliExpress aliexpress.com/item/1005004257411917.html
Digital caliper 150 mm | 1 | Tool: measure the servos before printing | AliExpress aliexpress.com/item/1005005671598813.html
Samsung 35E 18650 cell, 3500 mAh, button top | 2 | In the battery holder | TinkerTech AU tinkertechau.com.au/products/samsung-35e-
| | | 18650 (https://www.tinkertechau.com.au/products/samsung-35e-18650-3500mah-10a-battery-button-top)
Tinker 25R 18650 cell, 2500 mAh (spare pair) | 2 | Spare pair - never mix with the Samsungs | TinkerTech AU tinkertechau.com.au/products/tinker-25r- 18650- (https://www.tinkertechau.com.au/products/tinker-25r-18650-2500mah-20a-battery)
Heavy-duty hook-up wire 7.5 A, red (WH3040) | 2 m | Battery and servo power (+) | Jaycar jaycar.com.au/p/WH3040
Heavy-duty hook-up wire 7.5 A, black (WH3041) | 2 m | Battery and servo power (-) | Jaycar jaycar.com.au/p/WH3041
1000 uF 16 V capacitor (RE6220) | 2 | Hub: one across each Mini560 output | Jaycar jaycar.com.au/p/RE6220
2.2 kOhm resistors (RR0580) | 1 pack | Hub: wheel-stop pull-up on the OE line | Jaycar jaycar.com.au/p/RR0580
10 kOhm resistors (RR0596) | 1 pack | Hub: battery-level divider (top) | Jaycar jaycar.com.au/p/RR0596
4.7 kOhm resistors (RR0588) | 1 pack | Hub: battery-level divider (bottom) | Jaycar jaycar.com.au/p/RR0588
NBR O-ring assortment, OD 21-35 mm x 2.4 mm CS | 1 | Wheel tyres: use the 31 mm OD rings (about 26.2 mm inside), 4 + spares | AliExpress in store
Superglue 3 g (6 pack) | 1 | Only where the guide says | Bunnings in store
Cable ties 100 mm (25) | 1 | Hub anchors, slack loops | Bunnings in store
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

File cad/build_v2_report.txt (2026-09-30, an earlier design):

OK  Torso_Bottom        160.0 x  84.0 x  36.0 mm    98.6 g solid  bodies=1
OK  Battery_Clamp        52.0 x  10.0 x   3.0 mm     1.9 g solid  bodies=1
OK  Torso_Lid           160.0 x  84.0 x  20.5 mm    80.1 g solid  bodies=1
OK  Neck                 40.0 x  28.0 x  10.0 mm     5.9 g solid  bodies=1
OK  Head_Front          126.0 x  98.0 x  41.6 mm    68.8 g solid  bodies=1
OK  Head_Back           126.0 x  98.0 x   8.3 mm    42.4 g solid  bodies=1
OK  Screen_Washers      118.6 x  68.1 x   0.8 mm     0.1 g solid  bodies=4
ERR Muzzle             extrude failed
OK  Ear_Left             38.0 x  22.0 x  10.0 mm     9.0 g solid  bodies=1
OK  Ear_Right            38.0 x  22.0 x  10.0 mm     9.0 g solid  bodies=1
OK  Tail                 60.5 x  26.0 x  18.0 mm     3.7 g solid  bodies=1
OK  Thigh_FrontLeft      68.0 x  39.0 x   4.0 mm     5.0 g solid  bodies=1
OK  Shin_FrontLeft       72.5 x  39.0 x   4.0 mm     4.6 g solid  bodies=1
OK  Wheel_FrontLeft      26.4 x  26.4 x   8.0 mm     4.0 g solid  bodies=1
OK  Thigh_BackLeft       68.0 x  39.0 x   4.0 mm     5.0 g solid  bodies=1
OK  Shin_BackLeft        72.5 x  39.0 x   4.0 mm     4.6 g solid  bodies=1
OK  Wheel_BackLeft       26.4 x  26.4 x   8.0 mm     4.0 g solid  bodies=1
OK  Thigh_FrontRight     68.0 x  39.0 x   4.0 mm     5.0 g solid  bodies=1
OK  Shin_FrontRight      72.5 x  39.0 x   4.0 mm     4.6 g solid  bodies=1
OK  Wheel_FrontRight     26.4 x  26.4 x   8.0 mm     4.0 g solid  bodies=1
OK  Thigh_BackRight      68.0 x  39.0 x   4.0 mm     5.0 g solid  bodies=1
OK  Shin_BackRight       72.5 x  39.0 x   4.0 mm     4.6 g solid  bodies=1
OK  Wheel_BackRight      26.4 x  26.4 x   8.0 mm     4.0 g solid  bodies=1
OK  Fit_Test_Coupon      95.0 x  60.0 x  10.4 mm    24.0 g solid  bodies=1
    printed total 374 g solid, about 280 g as printed
OK  BOUGHT - every purchased part in place  bodies=132
CLASH CHECK: 157 bodies, 0 clashes
BALANCE: total 840 g, centre of mass x -0.2  y 36.6 (116 mm above the desk)  z +17.4 mm (feet at z +66 / -52)
  on 4 wheels: 48.6 mm inside the support area
  lift front left  foot:   -8.3 mm
  lift front right foot:   -8.5 mm
  lift rear right  foot:   +8.3 mm
  lift rear left   foot:   +8.5 mm
ASSEMBLY: 23 of 23 files inserted, each checked to sit at its modelled position

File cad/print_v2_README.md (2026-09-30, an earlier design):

# Desk Buddy - print model v2

Built by `build_print_parts_v2.py` (SolidWorks 2025). All parts share one coordinate frame, so the
assembly `print_v2\Desk Buddy v2 - full assembly.SLDASM` needs no mates and every clash is checked
body-against-body (report: `build_v2_report.txt`).

| Folder | What is in it |
|---|---|
| `print_v2\` | SolidWorks only: 23 printed parts, the bought-parts model, the assembly |
| `print_v2_stl\` | one STL per printed part (each checked against the model after export) |
| `print_v2_png\` | a picture of every part, 4 views of the assembly, and a sheet of all parts |

## Step 1 - print the Fit_Test_Coupon first (about 20 g, about an hour)

It has one of every critical fit. When the parts arrive, try each one:

1. **MG90S servo** drops into the slot with a little play, and its bag screws bite into the two slotted holes.
2. **KCD1 rocker switch** snaps into the rectangle and holds.
3. **Screen boss**: an M2 x 6 screw goes into the small post and grips.
4. **Clearance hole + counterbore**: an M2 screw slides through and its head sits flush.
5. **Horn pocket**: a double-arm servo horn drops into the pocket flush, and two small screws bite into the slots.
6. **O-ring groove**: a 22 mm O-ring stretches into the groove and stands a little proud of the rim.
7. **Laser and gesture windows**: hold the VL53L0X and APDS-9960 boards behind them. The sensor chip must show through.

If a fit is wrong, change the number in the MEASURE table at the top of the script, run it again, and
print the coupon again. Only then print everything else.

## Step 2 - measure these with the caliper when the parts arrive

Everything else was checked against published drawings. These were not published, so the model uses a
safe guess:

| Number in the script | Guess | What to measure |
|---|---|---|
| `SV_UNDER` | 21.0 | MG90S: case bottom to the underside of the mounting tabs |
| `SV_SPLINE` | 14.4 | MG90S: tab underside to the top of the output spline |
| `SV_TAB_T` | 2.8 | MG90S tab thickness |
| `SV_HOLES` | 28.15 | MG90S: centre-to-centre of the two tab holes (the model already allows +/-0.45) |
| `HORN_OUT`, `HORN_T`, `HORN_W`, `HORN_REACH`, `CROSS_REACH` | 1.0 / 1.8 / 6.6 / 17.5 / 11.5 | the horns in the servo bag: how far the arm face sits above the spline, arm thickness, arm width at the hub, centre-to-tip |
| `SCREEN_STACK` | 4.5 | Guition screen: front of the glass to the front of the circuit board |
| `OR_CS` | 2.4 | O-ring thickness (the 22 mm one from the Syneco kit) |
| camera board | 57 x 28 | ESP32-S3 CAM board: length, width, and which face the USB-C ports are on |
| speaker | 28 x 31 x 15 | the speaker box (the fences allow up to 30.6 x 33.6) |
| VL53L0X | small 10.5 x 13.8 or big 25 x 12 | which size arrived, and where the sensor chip is on it |

## Screws

Servo bags: 2 mounting screws + 1 horn screw per servo, 13 servos. From the M2 kit:

| Where | Count | Size |
|---|---|---|
| PCA9685 boards to the standoffs | 8 | M2 x 6 |
| Screen to the head | 4 | M2 x 6 |
| Lid to torso (front and back walls) | 4 | M2 x 8 |
| Neck to lid, neck to head | 8 | M2 x 8 |
| Head back cover (side walls) | 4 | M2 x 6 |
| Muzzle to head | 4 | M2 x 6 |
| Battery clamp | 2 | M2 x 8 |
| Horns to the printed legs, wheels and tail (if the servo bags have no small horn screws) | 26 | M2 x 6 (twist them through the horn holes) |

## Notes the model does not show

- **Hip swing:** keep each hip within about 30 degrees either way in software. At about 36 degrees the knee
  servo touches the bottom edge of the torso.
- **Wires:** the knee and wheel servo leads go up the leg and into the torso through the two floor slots
  beside each hip. Leave a loop of slack at each joint.
- **Capacitors on the hub board:** lay the 1000 uF capacitors on their side. There is 13 mm under the
  hub board.
- **KCD1 switch wires:** solder them and bend them sideways. There is about 8 mm above the terminals.

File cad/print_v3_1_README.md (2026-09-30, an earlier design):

# Desk Buddy - print model v3.1 (first print, about 10 Oct 2026)

This is the complete print pack for Desk Buddy, the desk robot dog. It is written for someone who has never
built it before. Read it top to bottom once, then use the tables while you print and assemble.

Everything here is made by `build_print_parts_v3_1.py` (SolidWorks 2025, driven from Python) and checked by the
same script. The raw results are in `build_v3_1_report.txt`. v1, v2 and v3 are untouched.

| Folder / file | What is in it |
|---|---|
| `print_v3_1\` | SolidWorks files only: the 55 robot parts, the 5 test prints, the bought-parts model, the full assembly |
| `print_v3_1_stl\` | one STL per printed part - these are what you print |
| `print_v3_1_png\` | a picture of every part, 7 views of the robot (iso, front, side, back, top, under, inside), and one exploded, labelled picture per body section |
| `build_v3_1_report.txt` | every check the script ran, with its numbers |

## What changed from v3 (and why)

The outside of the robot is exactly the approved v3: same shape, same three colours (warm white, graphite,
black caps), nothing new showing. All the changes are inside.

1. **Lighter.** The hidden walls are thinner:
   - head 2.4 -> 1.6 mm (the frame round the screen stays 2.4, so the glass sits exactly where it did)
   - tub side and end walls 2.4 -> 1.6 mm, plus a hidden window in each side wall behind the side panel
   - lid side and end walls 5.1 / 7.4 mm solid -> 1.6 mm, on a 1.8 mm locating lip
   - collar 2.4 -> 1.6 mm, muzzle sides and top 2.4 -> 1.8 mm
   - two small ribs inside the head back keep its big thin panel stiff

   1.6 mm is exactly 4 lines of a 0.4 mm nozzle, so these walls print solid and clean. Wherever a screw head,
   a servo or the screen presses on a thin wall there is a local pad, so those places are still 2.0 mm or more
   (the one exception is a tiny snap-detent recess; see "Decisions"). The grams are no longer a guess: the script
   slices every exported STL (see "Slicer settings"). Result: **385.7 g as printed** (v3: 393 g with the same
   settings, 457 g with 3 walls).
2. **Balance.** The perfboard hub under the lid sits 9 mm further back than in v3. The lighter lid and tub moved
   the weight forward, and this brings it back: 48.8 mm inside the wheels against 48.6 mm for v3 measured the
   same way (see "Numbers" for why the v3 report said 49.0).
3. **No clashes.** The tail cap's peg is 1.0 mm long instead of 1.2, so it stays 0.6 mm clear of the tail servo's
   horn even if the real horn is a little thicker than the estimate.
4. **Joint limits for the firmware.** One rear-leg pose (hip +30, knee +50) brings the paw pod to 0.9 mm under the
   belly. It never touches, but the firmware should keep 2 mm - see "Joint limits".
5. **Screw fixes found while checking lengths against the model** (v3 notes had these wrong):
   - touch-pad screws are **M2 x 4** (an M2 x 6 would come out through the top of the lid)
   - the horn-arm screws in the **thighs and the tail root are M2 x 4** (their pilots are only 2.2 mm deep)
   - the battery-door lugs in the tub are 0.8 mm taller, so the door takes the same M2 x 6 as everything else
6. The last v3 run had stopped in the assembly stage, so the v3 report was older than the v3 files. v3.1 rebuilt
   and re-checked everything from scratch.

## Before you print anything: measure the servos

The fits depend on a few numbers that the sellers do not publish. They are at the top of the script. When the
servos arrive, measure one with the caliper. If a number is off by more than about 0.2 mm, change it in
`build_print_parts_v3_1.py`, run the script again, and print from the new STLs.

| Number in the script | Value used | What to measure |
|---|---|---|
| `SV_TOP_RECT` | 4.5 | MG90S: underside of the mounting tabs to the top of the rectangular gear case |
| `SV_TOP_HUMP` | 7.5 | MG90S: underside of the tabs to the top of the round boss the spline comes out of (boss dia 11.8) |
| `SV_UNDER`, `SV_SPLINE`, `SV_TAB_T`, `SV_HOLES` | 21.0 / 14.4 / 2.8 / 28.15 | case bottom to tab underside, tab underside to spline top, tab thickness, tab hole spacing |
| tab ear corners | round, R1.1 or more | If your tab ears are square, file the two corners that face down to 1 x 45 deg |
| `LEAD_D` | 2.4 | twist the 3 servo wires into a round bundle; it must pass a 2.6 mm hole |
| `CROSS_REACH`, `HORN_T`, `HORN_W`, `HORN_OUT` | 11.5 / 1.8 / 6.6 / 1.0 | the cross horn in the servo bag: centre to tip, arm thickness, arm width, how far its top sits above the spline |
| `OR_CS` | 2.4 | the 26 mm ID O-ring's cross-section |

## Slicer settings (UltiMaker Cura, Ultimaker 2+ Connect, 0.4 mm nozzle, PLA)

The printed grams in this README assume exactly these settings. The script slices every exported STL with a
small voxel model of Cura's wall / skin / infill rules (`swlib_v3_1.stl_print_estimate`), checked against hand
calculations on test blocks to within 2 %.

| Setting | Value |
|---|---|
| Layer height | 0.2 mm |
| Line width | 0.4 mm |
| Wall line count | **2** (0.8 mm) |
| Top / bottom thickness | 0.8 mm (4 layers) |
| Infill | 15 %, gyroid |
| Supports | none (see note A) |
| Build plate adhesion | brim 5 mm on the long flat parts (plates G1 and W1), skirt on the rest |

**Why 2 walls.** The thin walls in v3.1 are 1.6 mm, exactly 4 lines of a 0.4 mm nozzle, so with 2 walls per side
they print completely solid (the few 1.8 mm walls get a thin gap fill in the middle). Screw bosses, pads and
seats are 2.0 mm or more and print solid as well. More walls only add plastic inside the thick parts (the leg
halves, wheels and ears), where 15 % gyroid is already enough.

What the settings change, for all 55 robot parts (from `build_v3_1_report.txt`):

| Walls | Printed grams | |
|---|---:|---|
| **2 walls (use this)** | **385.7 g** | under the 400 g budget limit with a 14 g margin |
| 2 walls, but 3 on the 8 leg outer halves | 394.3 g | stronger leg screw pilots; only 6 g of margin, so not the default |
| 3 walls everywhere | 422.6 g | over the limit |

Skirts, brims and the odd support add about 1-3 % on top, so expect Cura to say roughly 390-398 g in total.
Overall that is 70 % of the solid volume (the script's `FILL`, now measured: thin shells print at 95-100 %,
the thick leg halves, wheels and ears at 40-60 %).

**Note A - round edges on the bed.** The lid (R6 top edge), the head front (R8 face edge) and the head back
(R10 back edge) are printed with their visible face on the bed, so the first 1-2 mm of that rounded edge grows
outward over nothing. PLA normally prints this with a slightly soft first millimetre. If your first lid shows a
drooping edge, reprint that plate with "Support: touching build plate" at 60 deg, and sand the edge lightly.

## Every printed part

Grams are "as printed" with the settings above. "Plate" says which print job it goes on (next section).
`<leg>` is FrontLeft, FrontRight, BackLeft or BackRight.

| Part | Colour | What it holds | On the bed | Supports | g each | Plate |
|---|---|---|---|---|---:|---|
| `Torso_Bottom` (the tub) | graphite | 4 hip MG90S (tabs outside the wall), 2 PCA9685, protection board, fuse holder, USB-C charger, KCD1 switch, 5 VL53L0X | belly down | none | 49.7 | G1 |
| `Band_Chest` | graphite | front obstacle-laser window; hides 2 lid screws (2 snap hooks) | outer face down | none | 3.5 | G1 |
| `Band_Rump` | graphite | rear obstacle-laser window and the USB-C opening; hides 2 lid screws | outer face down | none | 3.4 | G1 |
| `Side_Panel_Left`, `Side_Panel_Right` | graphite | cover the 2 hip MG90S on their side (4 snap hooks each, no screws) | outer face down | none | 14.9 | G2 |
| `Battery_Door` | graphite | 2x18650 holder and the clamp; 4 screws into the tub | outer (belly) face down | none | 11.1 | G2 |
| `Battery_Clamp` | graphite | holds the 18650 holder down | flat | none | 1.3 | G2 |
| `Collar` | graphite | nothing (cables pass through it); joins the lid to the head | top face down | none | 12.4 | G2 |
| `Torso_Lid` | warm white | MPU6050, MPR121, perfboard hub (2 Mini560), tail MG90S, 2 side VL53L0X, 4 foil touch pads | top face down | note A | 46.0 | W1 |
| `Tail_Root` | warm white | the tail servo's cross horn, the tail cap | underside down | none | 1.6 | W1 |
| `Tail` | warm white | nothing (keyed onto the root, 1 hidden screw) | flat underside down | none | 1.1 | W1 |
| `Ear_Left`, `Ear_Right` | warm white | nothing (1 screw each from inside the head) | standing on the base | none | 2.5 | W1 |
| `Head_Front` | warm white | Guition 4.3in screen, 2 MS3625 mics, head touch pad, both ears | face (screen side) down | note A | 35.8 | W2 |
| `Muzzle` | warm white | ESP32-S3 CAM board, OV5640 camera, APDS-9960 gesture sensor | front face down | none | 11.4 | W2 |
| `Head_Back` | warm white | cavity speaker; clips onto the head front (5 snap hooks) | back face down | note A | 31.0 | W3 |
| `Thigh_<leg>_Outer` x4 | warm white | hip cross horn, knee MG90S (2 tab screws), 2 snap hooks | outer face down | none | 7.3 | 1 on W3, 3 on W4 |
| `Shin_<leg>_Outer` x4 | warm white | knee cross horn, wheel MG90S 360 (2 tab screws), 2 snap hooks | outer face down | none | 9.0 | W4 |
| `Thigh_<leg>_Cover` x4 | graphite | knee MG90S case (in the knee pod), leads | open side down | none | 7.2 | G3 |
| `Shin_<leg>_Cover` x4 | graphite | wheel MG90S 360 case (in the paw pod), leads, knee lead ring | open side down | none | 8.1 | G4 |
| `Wheel_<leg>` x4 | graphite | wheel cross horn, 26 x 2.4 O-ring tyre | outer face down | none | 2.9 | 3 on G3, 1 on G4 |
| `Cap_Hip_<leg>`, `Cap_Knee_<leg>` x8 | black | hide the hip and knee horn screws (dia 12) | top face down | none | 0.2 | B1 |
| `Cap_Wheel_<leg>` x4 | black | hide the wheel horn screws (dia 14) | top face down | none | 0.3 | B1 |
| `Cap_Tail` | black | hides the tail horn screw (dia 12) | top face down | none | 0.2 | B1 |
| `Port_Door_Head`, `Port_Blank_Head` | black | cover for the screen board's USB-C, and its matching blank | outer face down | none | 0.3 | B1 |
| `Port_Door_Muzzle`, `Port_Blank_Muzzle` | black | cover for the camera board's USB-C, and its matching blank | outer face down | none | 0.4 | B1 |
| `Screw_Plugs` (4 in one file) | black | hide the 4 battery-door screws | flat | none | 0.1 | B1 |
| `Screen_Washers` (4 in one file) | black | go under the 4 screen screws | flat | none | 0.1 | B1 |
| **Robot total (55 files)** | | | | | **385.7 g** | |
| `Fit_Test_Coupon` | any | test: servo slot, KCD1 cut-out, screen boss, windows, O-ring groove, horn pocket | flat | none | 14.5 | T1 |
| `Coupon_Knee_Thigh`, `Coupon_Knee_Shin` | any | test: knee MG90S, knee cross horn, cap, lead chamber | outer face down | none | 3.0, 5.6 | T1 |
| `Coupon_Snap_White`, `Coupon_Snap_Graphite` | any | test: one snap hook and catch, a dia 12 and a dia 14 cap seat | outer face down / flat | none | 2.3, 0.6 | T1 |

**Identical prints.** The front-left and rear-right thighs are the same shape turned round, and so are the
front-right and rear-left. The two left shins match, and so do the two right shins; all four wheels match, and
so do all the dia 12 caps. The files are separate only because each sits in its real place in the assembly.
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

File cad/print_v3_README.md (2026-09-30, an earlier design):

# Desk Buddy - print model v3 (covered design)

Built by `build_print_parts_v3.py` (SolidWorks 2025) from the approved design in
`v3_covered_design_proposal.md`. All parts share one coordinate frame, so the assembly
`print_v3\Desk Buddy v3 - full assembly.SLDASM` needs no mates and every clash is checked body
against body. The results are in `build_v3_report.txt`.

**Status (26 Sep 2026): the legs are v3.** The torso, lid, neck, head, muzzle, ears and tail are still
the v2 parts, painted in the v3 colours. The next build step turns them into v3 (side panels, collar,
tail turntable, battery door, belly switch). Until then the hip lead chambers are open on the body side,
and the tail still has its v2 horn.
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

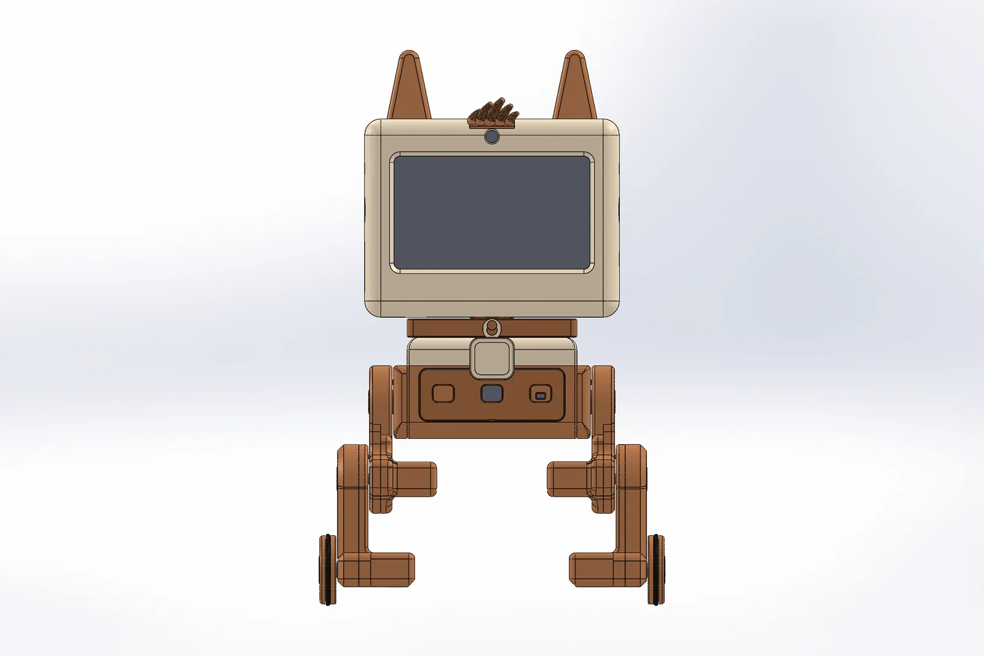
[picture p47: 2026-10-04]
docs/assets/img/cad/assembly-front.webp

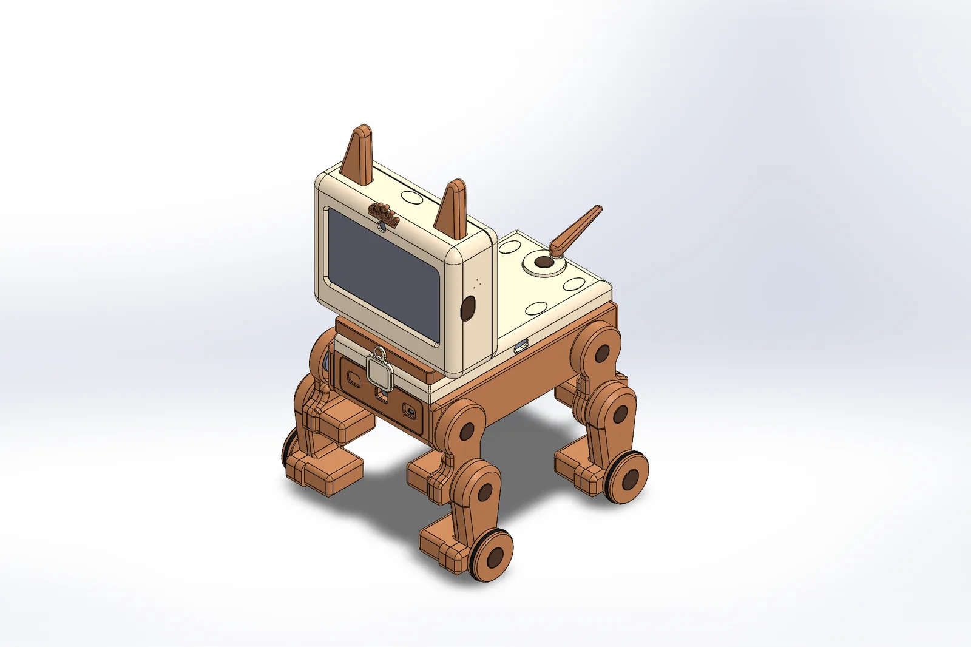
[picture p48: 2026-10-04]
docs/assets/img/cad/assembly-iso.webp

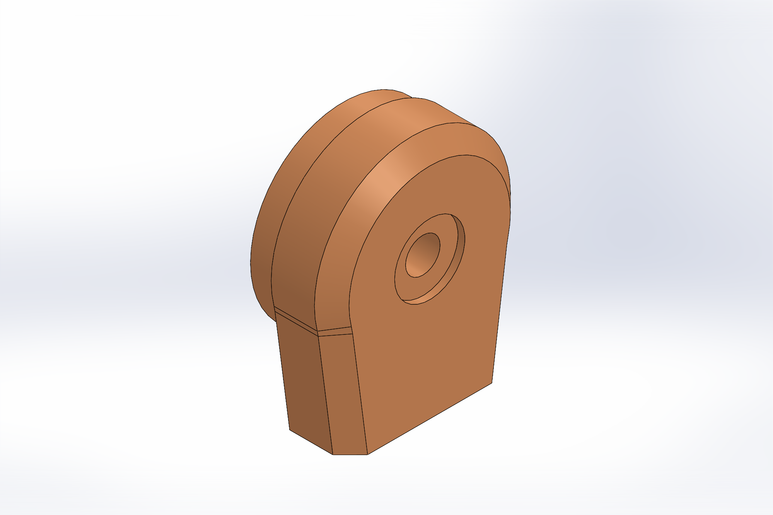
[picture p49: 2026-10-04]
cad/print_v3_2_png/Coupon_Knee_Shin (knee cross horn, lead chamber - test print).png

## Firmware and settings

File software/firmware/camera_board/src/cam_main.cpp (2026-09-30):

// cam_main.cpp -- Spike's camera board: OV5640 JPEG frames to the brain (protocol 6.8).
//   * frame size, frame rate and JPEG quality are settings (serial `cam ...`), default 320 x 240 at 5 fps
//   * never more than 10 fps, never a JPEG over 46 KiB (it raises the compression and drops that frame)
//   * frames exist only in memory; nothing is stored (privacy, protocol 6.8)
//   * setup like the screen board: serial console `help`, or the "Spike-Cam-Setup-xxxxxx" portal
//   * wireless updates (ArduinoOTA) once an update password is set (home Wi-Fi only)
//   * away from home it follows Spike to the phone's hotspot (cam_away.cpp, protocol v1.3 11.6)
#include "cam.h"
#include <esp_camera.h>
#include <esp_task_wdt.h>
#include <esp_mac.h>
#include <Preferences.h>
#include <WiFi.h>
#include <WebServer.h>
#include <DNSServer.h>
#include <ArduinoOTA.h>
#include <mbedtls/base64.h>
#include <esp_heap_caps.h>

#if ARDUINO_USB_MODE && !ARDUINO_USB_CDC_ON_BOOT
#include <HWCDC.h>
extern HWCDC USBSerial;
#define HAVE_USB 1
#endif

CamSettings cs;
static bool camOk = false;
static char* b64;           // base64 of one frame + the JSON fields
static size_t b64Cap;
static uint32_t seq = 0, sentFrames = 0, dropped = 0, lastStat = 0;

void logf(const char* fmt, ...) {
  char buf[256];
  va_list ap;
  va_start(ap, fmt);
  int n = vsnprintf(buf, sizeof buf - 2, fmt, ap);
  va_end(ap);
  if (n < 0) return;
  if (n > (int)sizeof buf - 3) n = sizeof buf - 3;
  buf[n++] = '\r';
  buf[n++] = '\n';
  Serial.write((const uint8_t*)buf, n);
#ifdef HAVE_USB
  if (USBSerial) USBSerial.write((const uint8_t*)buf, n);
#endif
}

const char* deviceId() {
  static char id[24] = {0};
  if (!id[0]) {
    uint8_t mac[6];
    esp_efuse_mac_get_default(mac);
    snprintf(id, sizeof id, "spikecam-%02x%02x%02x", mac[3], mac[4], mac[5]);
  }
  return id;
}

// ---- settings --------------------------------------------------------------------------------
static Preferences prefs;
static void getStr(const char* k, char* o, size_t n) { String s = prefs.getString(k, ""); strncpy(o, s.c_str(), n - 1); o[n - 1] = 0; }
void settingsLoad() {
  prefs.begin("spikecam", true);
  getStr("ssid", cs.ssid, sizeof cs.ssid);
  getStr("pass", cs.pass, sizeof cs.pass);
  getStr("host", cs.host, sizeof cs.host);
  getStr("token", cs.token, sizeof cs.token);
  getStr("ota", cs.otaPass, sizeof cs.otaPass);
  getStr("robot", cs.robotId, sizeof cs.robotId);
  cs.port = prefs.getUShort("port", BRAIN_DEFAULT_PORT);
  cs.frameSize = prefs.getUChar("size", FRAMESIZE_QVGA);
  cs.fps = prefs.getUChar("fps", 5);
  cs.quality = prefs.getUChar("q", 12);
  cs.vflip = prefs.getBool("vflip", false);
  cs.hmirror = prefs.getBool("hmirror", false);
  prefs.end();
  if (cs.fps < 1 || cs.fps > 10) cs.fps = 5;
  if (cs.quality < 6 || cs.quality > 40) cs.quality = 12;
  if (cs.frameSize < FRAMESIZE_QQVGA || cs.frameSize > FRAMESIZE_VGA) cs.frameSize = FRAMESIZE_QVGA;
}
void settingsSave() {
  prefs.begin("spikecam", false);
  prefs.putString("ssid", cs.ssid);
  prefs.putString("pass", cs.pass);
  prefs.putString("host", cs.host);
  prefs.putString("token", cs.token);
  prefs.putString("ota", cs.otaPass);
  prefs.putString("robot", cs.robotId);
  prefs.putUShort("port", cs.port);
  prefs.putUChar("size", cs.frameSize);
  prefs.putUChar("fps", cs.fps);
  prefs.putUChar("q", cs.quality);
  prefs.putBool("vflip", cs.vflip);
  prefs.putBool("hmirror", cs.hmirror);
  prefs.end();
}

// ---- camera ----------------------------------------------------------------------------------
static bool cameraBegin() {
  camera_config_t c = {};
  c.pin_pwdn = CAM_PIN_PWDN; c.pin_reset = CAM_PIN_RESET; c.pin_xclk = CAM_PIN_XCLK;
  c.pin_sccb_sda = CAM_PIN_SIOD; c.pin_sccb_scl = CAM_PIN_SIOC;
  c.pin_d7 = CAM_PIN_D7; c.pin_d6 = CAM_PIN_D6; c.pin_d5 = CAM_PIN_D5; c.pin_d4 = CAM_PIN_D4;
  c.pin_d3 = CAM_PIN_D3; c.pin_d2 = CAM_PIN_D2; c.pin_d1 = CAM_PIN_D1; c.pin_d0 = CAM_PIN_D0;
  c.pin_vsync = CAM_PIN_VSYNC; c.pin_href = CAM_PIN_HREF; c.pin_pclk = CAM_PIN_PCLK;
  c.xclk_freq_hz = 20000000;
  c.ledc_timer = LEDC_TIMER_0;
  c.ledc_channel = LEDC_CHANNEL_0;
  c.pixel_format = PIXFORMAT_JPEG;
  c.frame_size = (framesize_t)cs.frameSize;
  c.jpeg_quality = cs.quality;
  c.fb_count = 2;
  c.fb_location = CAMERA_FB_IN_PSRAM;
  c.grab_mode = CAMERA_GRAB_LATEST;  // always the newest frame, never a stale queue
  esp_err_t e = esp_camera_init(&c);
  if (e != ESP_OK) { logf("camera: init failed 0x%x -- check the pin map in cam.h against the seller's sheet", e); return false; }
  sensor_t* s = esp_camera_sensor_get();
  // Cheap copies can report the wrong chip id (BOM 2e): log it, but carry on.
  logf("camera: sensor PID 0x%04X (OV5640 = 0x5640), %s", s ? s->id.PID : 0, s && s->id.PID == OV5640_PID ? "OV5640" : "not an OV5640 id");
  if (s) { s->set_vflip(s, cs.vflip); s->set_hmirror(s, cs.hmirror); }
  return true;
}

static void sendFrame() {
  camera_fb_t* fb = esp_camera_fb_get();
  if (!fb) { dropped++; return; }
  if (fb->len > JPEG_MAX_BYTES) {  // too big for the protocol: compress harder from the next frame
    esp_camera_fb_return(fb);
    dropped++;
    sensor_t* s = esp_camera_sensor_get();
    if (s && cs.quality < 40) { cs.quality += 2; s->set_quality(s, cs.quality); logf("camera: frame over 46 KiB, JPEG quality -> %d", cs.quality); }
    return;
  }
  const size_t head = 96;
  size_t olen = 0;
  if (mbedtls_base64_encode((unsigned char*)b64 + head, b64Cap - head - 4, &olen, fb->buf, fb->len) != 0) {
    esp_camera_fb_return(fb);
    dropped++;
    return;
  }
  int w = fb->width, h = fb->height;
  esp_camera_fb_return(fb);
  b64[head + olen] = 0;
  char pre[head];
  int pn = snprintf(pre, sizeof pre, "\"seq\":%lu,\"format\":\"jpeg\",\"width\":%d,\"height\":%d,\"data\":\"", (unsigned long)++seq, w, h);
  char* start = b64 + head - pn;
  memcpy(start, pre, pn);
  b64[head + olen] = '"';
  b64[head + olen + 1] = 0;
  if (netSend("camera", start)) sentFrames++; else dropped++;
}

// ---- console + setup portal ----------------------------------------------------------------
static WebServer* web;
static DNSServer* dns;
static bool portal = false;
static uint32_t portalStart = 0, bootMs = 0;
static bool triedPortal = false;

bool portalActive() { return portal; }

static void page() {
  String h = F("<!doctype html><html><head><meta name=viewport content='width=device-width,initial-scale=1'><title>Spike camera setup</title>"
               "<style>body{font-family:sans-serif;max-width:420px;margin:20px auto;padding:0 12px}label{display:block;margin-top:12px}"
               "input{width:100%;padding:8px;font-size:16px}button{margin-top:18px;padding:10px 20px;font-size:16px}</style></head><body>"
               "<h2>Spike camera setup</h2><form method=post action=/save>");
  h += "<label>Home Wi-Fi name (2.4 GHz)<input name=ssid value=\"" + String(cs.ssid) + "\"></label>";
  h += F("<label>Wi-Fi password<input name=pass type=password></label>");
  h += "<label>Laptop brain address (IP)<input name=host value=\"" + String(cs.host) + "\"></label>";
  h += "<label>Brain port<input name=port value=\"" + String(cs.port) + "\"></label>";
  h += F("<label>Pairing token<input name=token type=password></label>");
  h += "<label>Robot id (the screen board's device id, e.g. spike-1a2b3c)<input name=robot value=\"" + String(cs.robotId) + "\"></label>";
  h += F("<label>Update password (optional)<input name=ota type=password></label><button>Save and restart</button></form></body></html>");
  web->send(200, "text/html", h);
}

static void save() {
  auto cp = [](const char* n, char* o, size_t sz, bool keep) { String v = web->arg(n); if (keep && !v.length()) return; strncpy(o, v.c_str(), sz - 1); o[sz - 1] = 0; };
  cp("ssid", cs.ssid, sizeof cs.ssid, false);
  cp("pass", cs.pass, sizeof cs.pass, true);
  cp("host", cs.host, sizeof cs.host, false);
  cp("token", cs.token, sizeof cs.token, true);
  cp("robot", cs.robotId, sizeof cs.robotId, false);
  cp("ota", cs.otaPass, sizeof cs.otaPass, true);
  int p = web->arg("port").toInt();
  cs.port = p > 0 && p < 65536 ? p : BRAIN_DEFAULT_PORT;
  settingsSave();
  web->send(200, "text/html", F("<html><body><h2>Saved. The camera restarts now.</h2></body></html>"));
  delay(800);
  ESP.restart();
}

static void startPortal() {
  if (portal) return;
  char ap[40];
  snprintf(ap, sizeof ap, "Spike-Cam-Setup-%s", deviceId() + 9);
  WiFi.mode(cs.ssid[0] ? WIFI_AP_STA : WIFI_AP);
  WiFi.softAP(ap);
  dns = new DNSServer();
  dns->start(53, "*", WiFi.softAPIP());
  web = new WebServer(80);
  web->on("/", HTTP_GET, page);
  web->on("/save", HTTP_POST, save);
  web->onNotFound(page);
  web->begin();
  portal = true;
  portalStart = millis();
  logf("setup: portal open -- join '%s' and open http://%s", ap, WiFi.softAPIP().toString().c_str());
}

static void command(char* line) {
  char* a[5] = {0};
  int n = 0;
  for (char* p = line; *p && n < 5;) {
    while (*p == ' ') p++;
    if (!*p) break;
    if (*p == '"') { a[n++] = ++p; while (*p && *p != '"') p++; }
    else { a[n++] = p; while (*p && *p != ' ') p++; }
    if (*p) *p++ = 0;
  }
  if (!n) return;
  if (!strcmp(a[0], "help")) {
    logf("status | wifi \"<name>\" \"<password>\" | brain <ip> [port] | token <t> | robot <screen-board-id>");
    logf("cam <qqvga|qvga|vga> <fps 1-10> <quality 6-40> | flip <0|1> <0|1> | otapass <p> | setup | reboot | factory-reset");
    logf("linkkey <64 hex> (from the screen board's 'linkkey') | linkkey | linkkey forget");
  } else if (!strcmp(a[0], "status")) {
    logf("%s fw %s | Wi-Fi '%s' %s | brain %s:%u %s | robot id %s | camera %s, %d fps, q %d | sent %lu dropped %lu", deviceId(),
         SPIKE_FW_VERSION, cs.ssid, WiFi.status() == WL_CONNECTED ? WiFi.localIP().toString().c_str() : "not connected", cs.host,
         cs.port, netConnected() ? "linked" : "not linked", cs.robotId[0] ? cs.robotId : "(own id)", camOk ? "ok" : "FAILED",
         cs.fps, cs.quality, (unsigned long)sentFrames, (unsigned long)dropped);
    logf("away: %s | link key %s", awayModeName(), awayLinkKeySet() ? "set" : "not set");
  } else if (!strcmp(a[0], "linkkey")) {
    awayLinkKeyCommand(n >= 2 ? a[1] : "");
  } else if (!strcmp(a[0], "wifi") && n >= 2) { strncpy(cs.ssid, a[1], sizeof cs.ssid - 1); strncpy(cs.pass, n >= 3 ? a[2] : "", sizeof cs.pass - 1); settingsSave(); logf("saved; reboot to use it"); }
  else if (!strcmp(a[0], "brain") && n >= 2) { strncpy(cs.host, a[1], sizeof cs.host - 1); cs.port = n >= 3 ? atoi(a[2]) : BRAIN_DEFAULT_PORT; settingsSave(); logf("saved; reboot to use it"); }
  else if (!strcmp(a[0], "token") && n >= 2) { strncpy(cs.token, a[1], sizeof cs.token - 1); settingsSave(); logf("saved"); }
  else if (!strcmp(a[0], "robot") && n >= 2) { strncpy(cs.robotId, a[1], sizeof cs.robotId - 1); settingsSave(); logf("saved; reboot to use it"); }
  else if (!strcmp(a[0], "otapass") && n >= 2) { strncpy(cs.otaPass, a[1], sizeof cs.otaPass - 1); settingsSave(); logf("saved; reboot to enable updates"); }
  else if (!strcmp(a[0], "cam") && n >= 4) {
    cs.frameSize = !strcmp(a[1], "vga") ? FRAMESIZE_VGA : (!strcmp(a[1], "qqvga") ? FRAMESIZE_QQVGA : FRAMESIZE_QVGA);
    int f = atoi(a[2]), q = atoi(a[3]);
    cs.fps = f < 1 ? 1 : (f > 10 ? 10 : f);
    cs.quality = q < 6 ? 6 : (q > 40 ? 40 : q);
    settingsSave();
    logf("saved camera %s %d fps quality %d; reboot to use it", a[1], cs.fps, cs.quality);
  } else if (!strcmp(a[0], "flip") && n >= 3) { cs.vflip = atoi(a[1]); cs.hmirror = atoi(a[2]); settingsSave(); logf("saved; reboot to use it"); }
  else if (!strcmp(a[0], "setup")) startPortal();
  else if (!strcmp(a[0], "reboot")) ESP.restart();
  else if (!strcmp(a[0], "factory-reset")) { prefs.begin("spikecam", false); prefs.clear(); prefs.end(); ESP.restart(); }
  else logf("unknown command -- type help");
}

static char lineBuf[200];
static int lineLen = 0;
static void feed(int ch) {
  if (ch == '\r' || ch == '\n') { if (lineLen) { lineBuf[lineLen] = 0; command(lineBuf); lineLen = 0; } }
  else if (lineLen < (int)sizeof lineBuf - 1) lineBuf[lineLen++] = (char)ch;
}

static bool otaStarted = false;
static void otaLoop() {
  if (awayHotspot()) return;  // no wireless updates on the phone's hotspot
  if (!otaStarted) {
    if (!cs.otaPass[0] || WiFi.status() != WL_CONNECTED) return;
    ArduinoOTA.setHostname(deviceId());
    ArduinoOTA.setPassword(cs.otaPass);
    ArduinoOTA.begin();
    otaStarted = true;
    logf("ota: ready as %s.local", deviceId());
  }
  ArduinoOTA.handle();
}

void setup() {
  Serial.begin(115200);
  delay(200);
  logf("\nSpike camera board firmware %s", SPIKE_FW_VERSION);
  esp_task_wdt_init(8, true);
  esp_task_wdt_add(nullptr);
  settingsLoad();
  if (!psramFound()) logf("WARNING: no PSRAM -- the camera needs it (board settings: OPI PSRAM)");
  b64Cap = (JPEG_MAX_BYTES + 2) / 3 * 4 + 256;
  b64 = (char*)heap_caps_malloc(b64Cap, MALLOC_CAP_SPIRAM | MALLOC_CAP_8BIT);
  camOk = cameraBegin();
  netBegin();
  awayBegin();
  bootMs = millis();
  if (!cs.ssid[0] || !cs.host[0]) { startPortal(); triedPortal = true; }
  logf("device %s ready -- type help", deviceId());
}

void loop() {
  esp_task_wdt_reset();
  while (Serial.available()) feed(Serial.read());
#ifdef HAVE_USB
  while (USBSerial.available()) feed(USBSerial.read());
#endif
  awayLoop();
  netLoop();
  otaLoop();
  // The setup portal opens by itself when the home Wi-Fi fails -- but not once a link key is set: then
  // the camera is set up, and away from home it must be free to hop channels for the hand-over.
  if (!triedPortal && !awayLinkKeySet() && WiFi.status() != WL_CONNECTED && millis() - bootMs > 60000) { startPortal(); triedPortal = true; }
  if (portal) {
    dns->processNextRequest();
    web->handleClient();
    if (millis() - portalStart > 15UL * 60 * 1000) { web->stop(); dns->stop(); WiFi.softAPdisconnect(true); portal = false; }
  }
  static uint32_t nextFrame = 0;
  uint32_t now = millis();
  if (camOk && netConnected() && (int32_t)(now - nextFrame) >= 0) {
    nextFrame = now + 1000 / cs.fps;
    sendFrame();
  }
  if (now - lastStat > 30000) {
    lastStat = now;
    if (netConnected()) logf("camera: %lu frames sent, %lu dropped", (unsigned long)sentFrames, (unsigned long)dropped);
  }
  delay(2);
}

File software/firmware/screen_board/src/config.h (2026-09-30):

// config.h -- every pin, address and tunable of the screen board in one place.
//
// Sources (see ../DESIGN.md "Pin map as used"):
//   * Guition JC4827W543C board pins: panel NV3041A on QSPI, GT911 touch, NS4168 amp -- the vendor
//     demo / Arduino_GFX board definition for this module (checked against the brief's "IO42/IO2/IO41").
//   * Robot wiring: MIRRORS guide/OPEN_QUESTIONS.md section D "Firmware pin and channel map", generated
//     from PINMAP in guide/src/data_wiring.py (the single source; guide/tools/servo_center uses the same).
//     The owner wires exactly the guide. tools/check_pinmap.py fails if this file and PINMAP disagree.
//     Servo / laser channels: lib/spike_body/src/spike_body.cpp kServoMap / kLaserMap.
#pragma once
#include <stdint.h>

// ---- display: NV3041A 480x272 over QSPI ------------------------------------------------------
#define PIN_LCD_CS 45
#define PIN_LCD_SCK 47
#define PIN_LCD_D0 21
#define PIN_LCD_D1 48
#define PIN_LCD_D2 40
#define PIN_LCD_D3 39
#define PIN_LCD_BL 1
#define LCD_SPEED_HZ 32000000UL   // NV3041A QSPI; vendor demos run 32 MHz
#define LCD_W 480
#define LCD_H 272

// ---- touch: GT911 on its own I2C bus (Wire1) --------------------------------------------------
#define PIN_TP_SDA 8
#define PIN_TP_SCL 4
#define PIN_TP_INT 3
#define PIN_TP_RST 38
#define TP_I2C_HZ 400000

// ---- audio ----------------------------------------------------------------------------------
// Onboard NS4168 class-D amp -> "Speak" port (brief: IO42 / IO2 / IO41)
#define PIN_SPK_BCLK 42
#define PIN_SPK_LRCK 2
#define PIN_SPK_DOUT 41
// 2 x MS3625 I2S mics on port P3 (guide S11/S12): SCK IO6, WS IO7, SD IO15; left mic L/R -> GND
#define PIN_MIC_SCK 6
#define PIN_MIC_WS 7
#define PIN_MIC_SD 15
#define SPEAKER_RATE 22050   // I2S out; offered to the brain first in hello.audio_out.rates
#define MIC_RATE 16000       // protocol 6.7: mono 16 kHz
#define MIC_CHUNK_MS 40      // protocol: 20..100 ms per chunk
#define MIC_MUTE_TAIL_MS 300 // BOM 2e: mute while speaking and 300 ms after

// ---- robot bus on port P4 (guide S1): I2C for both PCA9685, MPU6050, MPR121, APDS-9960, 7 lasers --
#define PIN_I2C_SDA 17
#define PIN_I2C_SCL 18
#define ROBOT_I2C_HZ 100000   // guide PINMAP: 100 kHz, one star-wired bus through the collar
#define PIN_SERVO_OE 14      // both PCA9685 OE; 2.2k pull-up to 3V3 -> HIGH = every output off
#define PIN_VBAT 5           // 10k (top) / 4.7k (bottom) divider from the switched battery
#define VBAT_DIVIDER ((10.0f + 4.7f) / 4.7f)

#define ADDR_MPU6050 0x68
#define ADDR_MPR121 0x5A
#define ADDR_APDS9960 0x39

// MPR121 electrodes (guide S10): E0 back-left, E1 back-right, E2 rump-left, E3 rump-right, E4 head
#define PAD_HEAD 4

// ---- timing ---------------------------------------------------------------------------------
#define FACE_FPS_TARGET 30
#define BODY_HZ 50
#define WDT_TIMEOUT_S 3      // task watchdog: reboot (OE floats high -> servos stop) if a task hangs
#define BODY_STALL_MS 300    // supervisor: OE high if the body task has not ticked for this long

// ---- network --------------------------------------------------------------------------------
#define BRAIN_DEFAULT_PORT 8765
#define SETUP_AP_PREFIX "Spike-Setup-"
#define WS_MAX_MESSAGE (70 * 1024)  // protocol: <= 64 KiB per message

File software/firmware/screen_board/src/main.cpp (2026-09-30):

// main.cpp -- Spike's screen board: boot, the face task, and the glue between the modules.
//
// The face task (core 1) owns Spike's life (lib/spike_life) and the face renderer (lib/spike_face):
// every frame it applies the queued commands (brain, touch, body, audio), steps the behaviour engine,
// draws the face into the PSRAM back buffer and hands it to the panel. It reports mood / action
// changes to the brain and tells the body which motion to play.
#include <Arduino.h>
#include <esp_task_wdt.h>
#include <esp_heap_caps.h>
#include <time.h>
#include "app.h"
#include "config.h"
#include "spike_face_draw.h"
#include "spike_raster.h"
#include "spike_life.h"
#include "spike_body.h"
#include "spike_passkey.h"

using namespace spike;

static QueueHandle_t cmdQ;

bool postCmd(const Cmd& c) { return cmdQ && xQueueSend(cmdQ, &c, 0) == pdTRUE; }

Cmd makeCmd(uint8_t type, int a, int b, float x, float y, const char* s) {
  Cmd c;
  c.type = type;
  c.a = (int16_t)a;
  c.b = (int16_t)b;
  c.x = x;
  c.y = y;
  c.s[0] = 0;
  if (s) { strncpy(c.s, s, sizeof c.s - 1); c.s[sizeof c.s - 1] = 0; }
  return c;
}

void bodySetInhibit(bool on);

// ---- Life hooks: sounds to the speaker, captions to the log ----------------------------------------
struct Hooks : LifeHooks {
  void playSound(Sound s, float arg) override { audioPlaySound((uint8_t)s, arg); }
  void caption(const char* text, bool literal, float) override {
    if (literal) logf("face: \"%s\"", text);
  }
};

// ---- face task state -----------------------------------------------------------------------------
static Hooks hooks;
static Life* life;
static Recipe recipes[2];  // [0] dog, [1] cat
static uint32_t lookAtMs = 0;
struct TouchState { bool down; int16_t x0, y0, x, y; uint32_t t0; HitZone zone; bool held, moved; uint32_t lastPat; };
static TouchState ts{};
static uint32_t padDown[5];
static bool padHeld[5];

static void loadRecipes() {
  recipes[0] = findPreset("classic")->recipe;
  recipes[1] = findPreset("spicy")->recipe;
  Recipe r;
  if (gSettings.recipeDog[0] && fromCode(gSettings.recipeDog, &r)) recipes[0] = r;
  if (gSettings.recipeCat[0] && fromCode(gSettings.recipeCat, &r)) recipes[1] = r;
}

static void sendTouch(const char* zone, const char* gesture) {
  char f[64];
  snprintf(f, sizeof f, "\"zone\":\"%s\",\"gesture\":\"%s\"", zone, gesture);
  netSend("touch", f);
}

static int hourNow() {
  time_t now = time(nullptr);
  if (now < 1700000000) return 12;  // clock not set yet (no Wi-Fi): assume the afternoon
  struct tm t;
  localtime_r(&now, &t);
  return t.tm_hour;
}

static void applyCmd(const Cmd& c) {
  Life& L = *life;
  switch (c.type) {
    case C_MOOD: {
      int m = moodIndex(c.s);
      if (m >= 0) { L.setMood(m); if (c.x > 0) L.setMoodHold(c.x); }
      break;
    }
    case C_ACTION:
      if (L.comfort(c.s)) { BodyCmd b{B_PLAY, 0, ""}; strncpy(b.label, c.s, sizeof b.label - 1); postBody(b); }
      else L.playAction(c.s);
      break;
    case C_EVENT:
      if (!strcmp(c.s, "sayHi")) L.sayHi();
      else if (!strcmp(c.s, "greetByTimeOfDay")) L.greetByTimeOfDay(hourNow());
      else if (!strcmp(c.s, "comeHome")) L.comeHome();
      else if (!strcmp(c.s, "ownerLooksSad")) L.ownerLooksSad();
      else if (!strcmp(c.s, "pickedUp")) L.pickedUp();
      else if (!strcmp(c.s, "fellOver")) L.fellOver();
      else if (!strcmp(c.s, "ignoredNudge")) L.ignoredNudge();
      break;
    case C_SOUND: {
      bool ok;
      Sound s = soundFromProtocolName(c.s, &ok);
      if (ok) audioPlaySound((uint8_t)s, 0);
      break;
    }
    case C_LOOK: L.setLook(c.x, c.y); lookAtMs = millis(); break;
    case C_MODE:
      if ((c.a != 0) != L.cat()) {
        L.setMode(c.a != 0);
        gSettings.cat = c.a != 0;
        settingsSave();
      }
      break;
    case C_RECIPE_CODE: {
      Recipe r;
      if (fromCode(c.s, &r)) {
        recipes[c.a ? 1 : 0] = r;
        strncpy(c.a ? gSettings.recipeCat : gSettings.recipeDog, c.s, sizeof gSettings.recipeDog - 1);
        settingsSave();
      }
      break;
    }
    case C_LISTEN: L.setListening((Listen)c.a); break;
    case C_ALARM: L.alarm((AlarmState)c.a, c.b); break;
    case C_GAME:
      if (c.a == 0) L.gameStart();
      else if (c.a == 3) L.rpsReact(c.b);
      break;
    case C_BATTERY: L.setBattery(c.x); break;
    case C_SAFETY:
      switch ((body::SafetyEvent)c.a) {
        case body::EV_EDGE_FL: case body::EV_EDGE_FR: case body::EV_EDGE_REAR: L.edgeFear(); break;
        case body::EV_PICKUP: L.pickedUp(); break;
        case body::EV_FALL: L.fellOver(); break;
        default: break;
      }
      break;
    case C_SPEECH_START: {
      int m = moodIndex(c.s);
      if (m >= 0) L.setMood(m);
      L.markInteraction();
      break;
    }
    case C_TOUCH_PAD: {
      int e = c.a;
      if (e < 0 || e > 4) break;
      const char* zone = e == PAD_HEAD ? "head" : "back";
      if (c.b) {
        padDown[e] = millis();
        padHeld[e] = false;
        L.pat();
        sendTouch(zone, e == PAD_HEAD ? "tap" : "pat");
      } else if (padHeld[e]) sendTouch(zone, "release");
      break;
    }
    case C_GESTURE: if (c.a) L.handWave(); else L.handNear(); break;
    case C_BRAIN_UP: break;
    case C_BRAIN_DOWN: break;
    case C_HELLO_NAMES: logf("face: names from the brain: %s", c.s); break;
    default: break;
  }
}
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

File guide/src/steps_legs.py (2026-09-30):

# Desk Buddy guide - assembly steps, part 3: D Legs, E Tail, F Ears.
# Leg geometry (front-left leg, x > 0 is the robot's left): hip axis y 18, knee y -20, wheel axle y -65,
# front hips z +66, rear hips z -52. Thigh outer half x 55.6-60.6, shin outer 66.4-76.4, wheel 77.2-85.2.

def leg_parts(offsets=None, keep=None):
    """All printed parts of the robot in place (for overview views)."""
    body = [('Torso_Bottom', 'graphite'), ('Torso_Lid', 'white'), ('Side_Panel_Left', 'graphite'),
            ('Side_Panel_Right', 'graphite'), ('Band_Chest', 'graphite'), ('Band_Rump', 'graphite'),
            ('Collar', 'graphite'), ('Head_Front', 'white'), ('Head_Back', 'white'), ('Muzzle', 'white'),
            ('Ear_Left', 'white'), ('Ear_Right', 'white'), ('Tail_Root', 'white'), ('Tail', 'white')]
    for leg in ('FrontLeft', 'FrontRight', 'BackLeft', 'BackRight'):
        body += [(f'Thigh_{leg}_Outer', 'white'), (f'Thigh_{leg}_Cover', 'graphite'), (f'Shin_{leg}_Outer', 'white'),
                 (f'Shin_{leg}_Cover', 'graphite'), (f'Wheel_{leg}', 'graphite'), (f'Cap_Hip_{leg}', 'black'),
                 (f'Cap_Knee_{leg}', 'black'), (f'Cap_Wheel_{leg}', 'black')]
    return [(n, c, (0, 0, 0)) for n, c in body if keep is None or n in keep]


FL_THIGH = ('Thigh_FrontLeft_Outer', 'white', (0, 0, 0))
FL_THIGH_COVER = ('Thigh_FrontLeft_Cover', 'graphite', (0, 0, 0))
FL_SHIN_COVER = ('Shin_FrontLeft_Cover', 'graphite', (0, 0, 0))

STEPS_D = [
    dict(id='D1', title='Which leg is which',
         img=('stl', dict(parts=leg_parts(), cam=(-25, 62), width=1500, labels=[
             ((70, -30, 75), 'FRONT-LEFT: knee servo points forward', 'a'),
             ((-70, -30, 75), 'FRONT-RIGHT', 'a'),
             ((70, -30, -60), 'BACK-LEFT: knee servo points backward', 'a'),
             ((-70, -30, -60), 'BACK-RIGHT', 'a'),
             ((0, 158, 60), 'head = front', 'a'),
         ])),
         need=[('part', 'for each leg: thigh outer + cover, shin outer + cover, wheel, 3 caps'), ('part', 'per leg: 2 MG90S 180 (knee) and 1 MG90S 360 (wheel), all centred')],
         text=['The four legs are built the same way. The pictures in this chapter show the front-left leg; build the other three the same.',
               'Each printed file has its leg in the name, for example Thigh_FrontLeft_Outer. Some shapes are identical, so if you mix two up nothing is lost: the front-left and back-right thighs are the same shape turned round, and so are the front-right and back-left. The two left shins match, the two right shins match, and all four wheels match.',
               'The knee servo body always points away from the middle of the robot: forward on the front legs, backward on the back legs. Every paw (the wheel servo body) points forward.'],
         check='Lay out the four sets on the table in the shape of the robot before you start.',
         mistake='Mixing a left shin with a right leg. Left and right shins are mirror images and do not fit the other side.'),

    dict(id='D2', title='Hip horn into the thigh',
         img=('stl', dict(parts=[FL_THIGH], cam=(-68, 22), width=1300, labels=[
             ((55.6, 18, 66), 'hip horn pocket: 2 x M2x4', 'a'),
             ((55.6, -20, 57.3), 'knee servo tab holes', 'a'),
             ((55.6, -9, 66), 'lead hole at 12 o\'clock', 'a'),
             ((54, 4, 66), 'hip cup lead window (6 o\'clock)', 'a'),
         ])),
         need=[('part', 'thigh outer half'), ('part', 'a 4-arm cross horn from a servo bag'), ('part', '2.0 mm drill bit (turned by hand)'), ('screw', 2, 'M2x4')],
         text=['The holes in the servo horns are about 1.5 mm, too small for an M2 screw. Pick the two opposite arms you will use and open one hole on each to 2 mm by turning the drill bit between your fingers. Use holes between 6.7 and 10 mm from the horn\'s centre.',
               'Lay the horn in the cross-shaped pocket on the inside face of the thigh, at the hip end, with its hub facing out of the pocket, and drive 1 x M2x4 through each opened hole.'],
         check='The horn sits flat in its pocket and cannot turn.',
         mistake='Using M2x6 here. The thigh is thin at the hip, and a longer screw comes out through its outer face.'),

    dict(id='D3', title='Knee servo onto the thigh',
         img=('sec', '4 Leg', dict(crop='hi', hi=['Thigh_Outer'], hi2=['knee MG90S'], labels=[('knee MG90S', 'knee servo, body pointing away from the body', 'a', 0)])),
         need=[('part', 'MG90S 180, centred, lead flagged K + leg name'), ('screw', 2, 'M2x6')],
         text=['Set the knee servo onto the knee end of the thigh outer half, tabs flat on the face, with the round output boss in the round bore. Its body points away from the middle of the robot: forward on a front leg, backward on a back leg.',
               'Fix it with 2 x M2x6 through the tabs into the blind holes. The knee servo\'s lead leaves the body at the end nearest the knee.'],
         check='The servo spline sits in the middle of the bore and the tabs touch the face all the way along.',
         mistake='Turning the servo round so its body points toward the robot\'s middle. It will then hit the belly when the leg swings.'),

    dict(id='D4', title='Knee horn and wheel servo onto the shin',
         img=('sec', '4 Leg', dict(crop='hi', hi=['Shin_Outer'], hi2=['wheel MG90S 360'], labels=[('Shin_Outer', 'shin outer half', 'a', 0), ('wheel MG90S 360', 'wheel servo (360), body forward', 'a', 0)])),
         need=[('part', 'shin outer half'), ('part', 'cross horn (two holes opened to 2 mm)'), ('part', 'MG90S 360, lead flagged W + leg name'), ('screw', 4, 'M2x6')],
         text=['At the knee end of the shin outer half there is a cross-shaped pocket, just like the thigh\'s. Lay a horn in it, hub facing out, and fix it with 2 x M2x6.',
               'At the paw end, set the wheel servo (the 360 degree one) with its tabs on the face and its round boss in the bore, body pointing forward on every leg. Fix it with 2 x M2x6.'],
         check='Both screws of each pair are the same length. The knee horn screws here are M2x6, unlike the thigh.',
         mistake='Fitting a 180 degree servo in the paw. The wheel servos are the 360 degree ones from the pack of four.'),

    dict(id='D5', title='Horn into the wheel',
         img=('sec', '4 Leg', dict(crop='hi', hi=['Wheel'], labels=[('Wheel', 'wheel: horn pocket on the inner face', 'a', 0)])),
         need=[('part', 'wheel'), ('part', 'cross horn (two OUTER holes opened to 2 mm)'), ('screw', 2, 'M2x6')],
         text=['Lay a horn in the cross-shaped pocket on the inner face of the wheel, hub facing out, and fix it with 2 x M2x6 through the outer holes, at least 7.6 mm from the centre.',
               'Put the wheel aside for now. It goes on after the shin cover.'],
         check='The horn is flat in the pocket.',
         mistake='Using the inner horn holes. The screw then misses the thicker part of the wheel.'),
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

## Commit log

2026-09-30 Spike (Desk Buddy) source, viewing only — all rights reserved
    [BOUGHT - every purchased part in place.SLDPRT, Band_Chest (front obstacle VL53L0X window, covers 2 lid screws).SLDPRT, Band_Chest (front obstacle VL53L0X windo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]
2026-10-04 CAD v3.2 (forehead tuft camera), 3D previews v7-v7.2, Store screenshots for app 1.0.1
    Print model v3.2 with build, servo-load and stability scripts and their reports; 3D shell previews v7, v7.1 and v7.2 with rendered views; Microsoft Store screenshots of the desktop app 1.0.1. Old Tuft_Mask parts are ignored (superseded by the v3.2 Tuft).
    [BOUGHT - every purchased part in place.SLDPRT, Ballast_Cover_Left (closes the left rump ballast pocket).SLDPRT, Ballast_Cover_Left (closes the left rump ballas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]
2026-10-13 Website: dark by default; dusky field shows through the exploded view (stage=none, exploded-view 1.6.0)
2026-10-13 Website: camera-view chips and part card follow the dark theme (exploded-view 1.6.1)
2026-10-13 Website: full-screen button on the Inside Spike explorer (exploded-view 1.7.0)
2026-10-16 Build guide: 18 new part photos, printed pad names on the protection and charge boards
2026-10-17 Easy picture build guide, printer guide, guide data fixes
2026-10-17 Guide: servo-board wiring fix, wheel choice
2026-10-17 Guide: servo-board wiring fix, wheel choice, soldered hub leads, hot-glue step
